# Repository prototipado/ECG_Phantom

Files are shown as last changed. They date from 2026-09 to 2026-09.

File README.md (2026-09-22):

# Fantoma ECG






Simulador y calibrador de señales electrocardíacas multicanal. Este proyecto integra el diseño de hardware analógico/digital, simulaciones de filtrado en LTSpice, implementaciones de firmware para RP2040 y RP2350, y software de control en Python.

## Arquitectura del sistema

```mermaid
flowchart TD
    subgraph HW["Hardware y Señal"]
        MCU["RP2040 / RP2350<br/>(Raspberry Pi Pico)"]
        FILT["Filtros Reconstrucción PWM/DAC<br/>(Simulados en LTSpice)"]
        OUT["Salida 9-12 Derivaciones ECG + PPG"]
        MCU --> FILT --> OUT
    end
    subgraph FW["Firmware"]
        FW1["01. Reproductor Clínico (Flash/PhysioNet)"]
        FW2["02. Modelo Conducción (VdP + FHN)"]
        FW3["03. Síntesis Gaussiana + PPG"]
        FW4["04. Multi-Modelo 4-en-1"]
        FW5["05. Simulador Marcapasos (Pacer)"]
    end
    FW -.->|Carga según aplicación| MCU
    subgraph SW["Software Host"]
        PY["ecg_gui.py (Python)"]
        PLOT["Monitoreo multicanal en tiempo real"]
        CFG["Configuración de parámetros"]
        PY --> PLOT
        PY --> CFG
    end
    MCU <== "Streaming Serie USB (Handshake binario / 2000 SPS)" ==> PY
```

## Estructura del repositorio

* [`hardware/`](./hardware/): Proyecto KiCad (`pico_ecg`), esquemáticos, PCB, huellas, modelos 3D, Gerber y BOM.
* [`simulaciones/`](./simulaciones/): Circuitos LTSpice para filtrado analógico (PWM a voltaje), detección de impulsos y scripts en Python.
* [`firmware/`](./firmware/): Código para Raspberry Pi Pico y Pico 2:
  * [`01_pico_ecg`](./firmware/01_pico_ecg/): Reproductor de registros clínicos guardados en memoria Flash.
  * Módulos adicionales en desarrollo (`02_pico_conduction_model` a `05_pace_sim`).
* [`software/`](./software/): Interfaz de escritorio en Python para visualización multicanal, registro de datos y control remoto.
* [`datasets/`](./datasets/): Registros de bases clínicas (PhysioNet, LUDB) y scripts para convertirlos a arreglos en C (`.h`).
* [`docs/`](./docs/): Protocolo de comunicación, referencias bibliográficas y notas de diseño.

## Características

* Salida de derivaciones estándar (I, II, III, aVR, aVL, aVF, V1-V6) y canal auxiliar PPG.
* Generación analógica a electrodos y transmisión serie por USB (hasta 2000 SPS).
* Control local mediante menú en pantalla OLED y encoder rotativo, o remoto desde la GUI en Python.
* Simulación de ritmos normales y patologías (taquicardia, bradicardia, fibrilación, bloqueos AV, deriva de línea base).

## Inicio rápido

### Dependencias de software (GUI)

```bash
cd software
python -m venv .venv

# En Windows:
.venv\Scripts\activate

# En Linux/macOS:
source .venv/bin/activate

pip install -r requirements.txt
python ecg_gui.py
```

### Carga de firmware

1. Navegar a la carpeta del firmware deseado (por ejemplo, [`firmware/01_pico_ecg/`](./firmware/01_pico_ecg/)).
2. Conectar la Raspberry Pi Pico manteniendo presionado el botón BOOTSEL.
3. Copiar el archivo `.uf2` compilado a la unidad USB generada.

## Estado del desarrollo

- [x] Caracterización y simulación de filtros pasa-bajos en LTSpice.
- [x] Firmware base `01_pico_ecg` para reproducción de registros clínicos.
- [ ] Desarrollo e integración de firmwares sintéticos (`02_pico_conduction_model` a `05_pace_sim`).
- [x] Diseños finales de PCB y acondicionamiento de señal en KiCad.
- [x] GUI en Python para captura en tiempo real, registro a CSV y compilación a ejecutable.

## Licencia

Este proyecto está bajo la Licencia MIT. Ver el archivo [`LICENSE`](./LICENSE) para más detalles.

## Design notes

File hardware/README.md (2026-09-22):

# Diseño de Hardware (KiCad)

Este directorio contiene el diseño electrónico y mecánico del Fantoma ECG, organizado como un proyecto unificado en KiCad.

## Estructura del proyecto

### Archivos de diseño KiCad

- **`pico_ecg.kicad_pro`**: Archivo principal del proyecto KiCad.
- **`pico_ecg.kicad_sch`**: Esquema de circuito principal (etapa analógica, microcontrolador y conectores).
- **`filtros.kicad_sch`**: Sub-esquema de la etapa de filtrado analógico.
- **`pacemaker.kicad_sch`**: Sub-esquema del simulador de marcapasos.
- **`pico_ecg.kicad_pcb`**: Ruteo de la placa de circuito impreso (PCB).

### Directorios

- **`pico_ecg.pretty/`**: Librería de huellas (footprints) locales utilizadas en el diseño — incluye huellas para OLED, Raspberry Pi Pico, cargador TP4056, encoder rotativo, entre otros.
- **`3d_models/`**: Modelos 3D de componentes (STEP/WRL) para visualización en KiCad — incluye Raspberry Pi Pico, OLED 0.96", cargador LiPo, encoder rotativo, y el ensamblaje completo (`pico_ecg.step`).
- **`case/`**: Archivos STL para impresión 3D del gabinete del dispositivo (`base.stl`, `frente.stl`) y fotografías del ensamblaje.
- **`gerber/`**: Archivos de fabricación (Gerber) y de perforación (Drill) listos para enviar a fabricación.
- **`bom/`**: Lista de materiales (`pico_ecg_BOM.csv`) con referencias de componentes, valores y huellas.
- **`docs/`**: Esquemático exportado en PDF (`pico_ecg.pdf`) para revisión rápida sin necesidad de KiCad.
- **`images/`**: Renderizados de la PCB y esquemas de filtrado.

## Imágenes

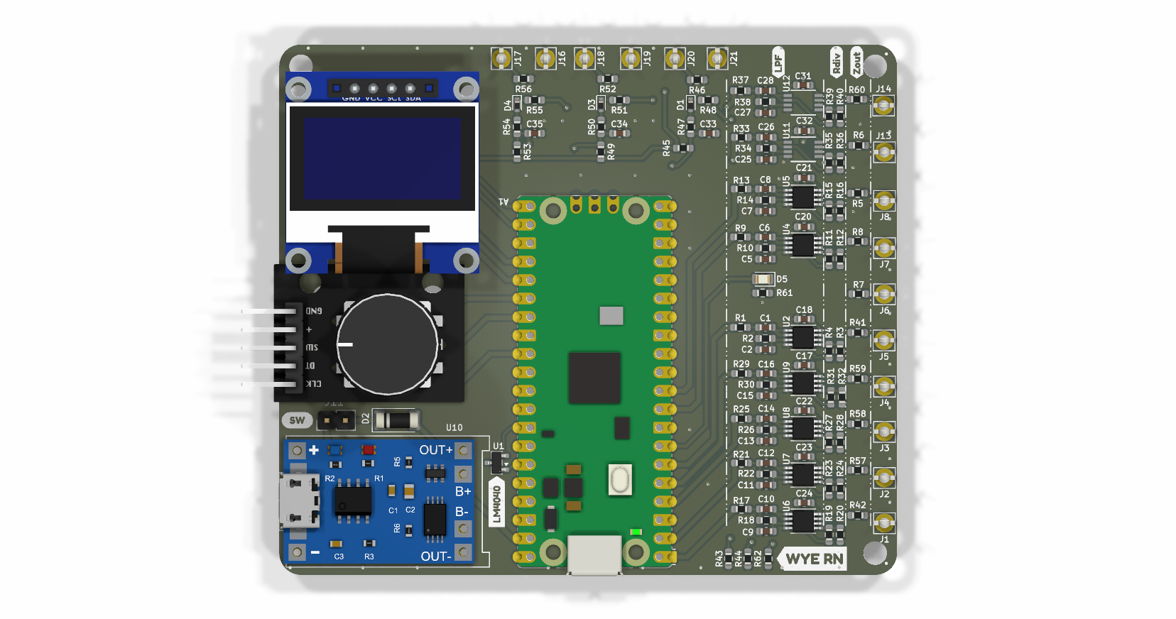
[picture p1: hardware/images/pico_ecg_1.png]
PCB renderizado — vista frontal

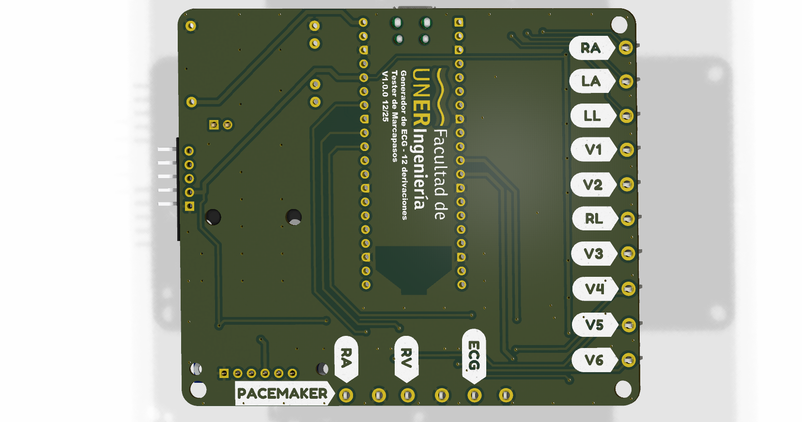
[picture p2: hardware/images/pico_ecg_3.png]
PCB renderizado — vista trasera


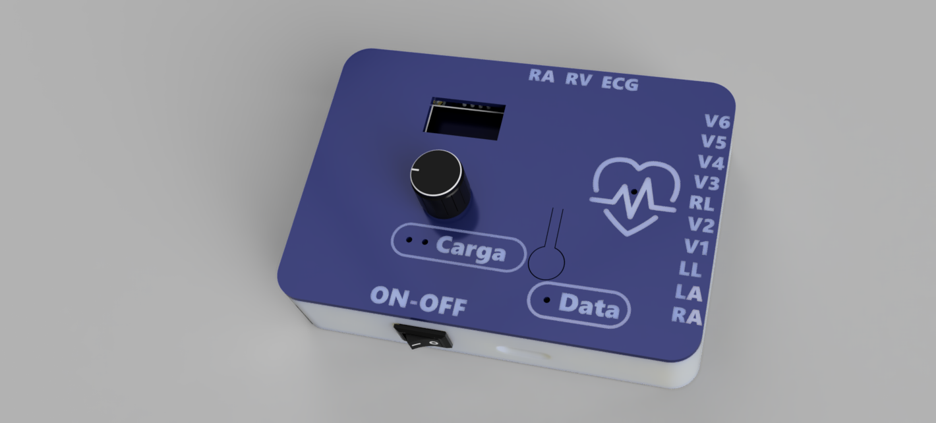
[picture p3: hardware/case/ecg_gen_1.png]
Generador ECG con carcasa impresa en 3D

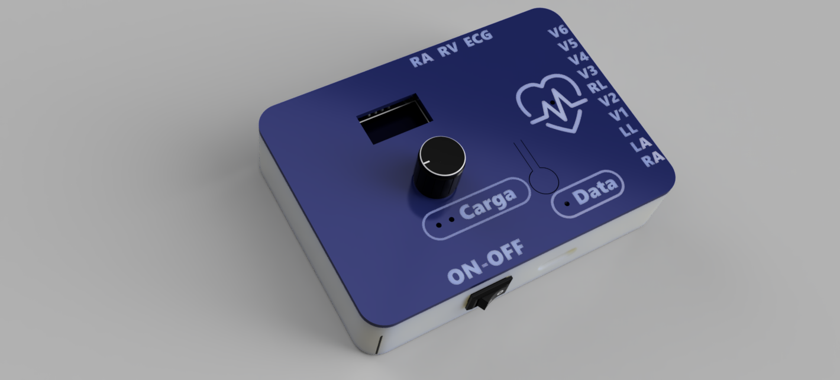
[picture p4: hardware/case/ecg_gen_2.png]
Generador ECG — vista lateral


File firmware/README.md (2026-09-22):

# Firmwares de Emulación Cardíaca (RP2040 / RP2350)

Este directorio alberga los módulos de firmware diseñados para microcontroladores Raspberry Pi Pico y Pico 2 (RP2040 / RP2350). Cada firmware aborda un método distinto de síntesis o reproducción de señales electrofisiológicas.

## Matriz de firmwares

| Carpeta | Nombre / Enfoque | Estado | Método de Generación | Salidas Soportadas | Complejidad Computacional |
|---|---|---|---|---|---|
| **`01_pico_ecg`** | Reproductor Clínico | Disponible | Lectura directa de Flash/RAM (PhysioNet) | 1 a 12 derivaciones | Baja (Look-up Table / DMA) |
| **`02_pico_conduction_model`** | Modelo Electrofisiológico | En desarrollo | Ecuaciones diferenciales acopladas (Van der Pol + FHN) | Derivaciones bipolares / derivaciones sintéticas | Media-Alta (Cálculo numérico RK4/Euler) |
| **`03_pico_gaussian_ppg`** | Síntesis Analítica + PPG | Planificado | Suma de curvas Gaussianas dinámicas | 9 derivaciones ECG + Pulso Óptico PPG | Media |
| **`04_pico_multimodel`** | Suite Multi-Motor 4-en-1 | Planificado | Selector de motor matemático en caliente | Multicanal configurable | Alta |
| **`05_pace_sim`** | Simulador de Marcapasos | Planificado | Inyección de espigas analógicas/digitales con tiempos configurables | Salida de estimulación cardíaca | Baja-Media |

## Módulo inicial: `01_pico_ecg`

Plataforma de reproducción de señales clínicas reales almacenadas en memoria Flash:
- **Salida multicanal:** 9 potenciales analógicos de electrodos (RA, LA, LL, V1–V6) generados vía moduladores PWM a 100 kHz.
- **Interfaz local:** Menú gráfico en pantalla OLED (SSD1306/SH1106 vía SPI) administrado con encoder rotativo mediante la librería GEM y u8g2.
- **Consola interactiva CLI USB:** Comandos serie (`> set`, `> get`, `> list`, `> play`, `> stop`, `> stream on/off`, `> ver`).
- **Streaming de alta velocidad:** Transmisión binaria IEEE 754 a 500 SPS compatible con `software/ecg_gui.py`.
- **Indicación auditiva y visual:** LED indicador y buzzer piezoeléctrico sincronizados con la onda R (complejo QRS).
- *Documentación detallada, pinout completo y comandos:* Consultar [firmware/01_pico_ecg/README.md](./01_pico_ecg/README.md).

## Componentes compartidos (`common/`)

Para evitar duplicar código, el directorio `common/` centraliza módulos compartidos configurados como librerías estáticas de CMake:

```text
firmware/
├── common/
│   ├── CMakeLists.txt     # Define los targets estáticos 'u8g2' y 'gem'
│   ├── GEM/               # Graphic Embedded Menu
│   └── u8g2/              # Librería gráfica u8g2/u8x8
├── 01_pico_ecg/           # Firmware de reproducción
└── 02_.../                # Otros firmwares
```

### Targets disponibles en `common`

1. **`u8g2`**: Compila el motor gráfico universal de displays monocromáticos.
2. **`gem`**: Compila el sistema de menús embebidos interactivo para encoders. Enlaza a `u8g2` de forma `PUBLIC`, heredando sus archivos de cabecera.

### Cómo integrar `common` en un nuevo firmware

Para crear un nuevo firmware (ej. `02_pico_conduction_model`) que haga uso de GEM y u8g2, en su `CMakeLists.txt` se debe:

```cmake
# 1. Registrar el subdirectorio 'common'
add_subdirectory(${CMAKE_CURRENT_LIST_DIR}/../common ${CMAKE_CURRENT_BINARY_DIR}/common_build)

# 2. Agregar el ejecutable
add_executable(mi_firmware 
    main.c
)

# 3. Vincular 'gem' (propaga u8g2 automáticamente)
target_link_libraries(mi_firmware 
    gem
    pico_stdlib
    hardware_spi
)
```

Nota: CMake propaga automáticamente las rutas de include públicas (`common/GEM` y `common/u8g2/csrc`) a cualquier ejecutable que enlace la librería `gem` o `u8g2`.

## Guía de compilación

Todos los firmwares utilizan el Raspberry Pi Pico SDK (v2.x) y CMake.

### 1. Requisitos previos

- Raspberry Pi Pico SDK 2.x instalado (`PICO_SDK_PATH`).
- Toolchain GCC para ARM Cortex-M: `arm-none-eabi-gcc` (v12 o superior).
- CMake (v3.13 o superior) y Ninja (recomendado).
- Opcional: Visual Studio Code con la extensión oficial de Raspberry Pi Pico.

### 2. Compilación desde la terminal

Navegar a la carpeta del firmware que se desea compilar:

```powershell
# Entrar al firmware
cd firmware/01_pico_ecg

# Generar los archivos de compilación
cmake -G Ninja -B build -S .

# Compilar
ninja -C build
```

Si no se dispone de Ninja:
```powershell
cmake -B build -S .
cmake --build build
```

### 3. Compilación desde Visual Studio Code

1. Abrir la carpeta del firmware (por ejemplo `firmware/01_pico_ecg`) en VS Code.
2. La extensión de Raspberry Pi Pico detectará el archivo `.vscode/settings.json`.
3. Presionar `Ctrl + Shift + B` o hacer clic en "Compile Project".

### 4. Carga en la placa (flasheo)

En la carpeta `build/` se generará un archivo `.uf2`:

1. Conectar la Raspberry Pi Pico / Pico 2 a la PC manteniendo presionado el botón BOOTSEL.
2. Aparecerá una unidad de almacenamiento USB (`RPI-RP2` o `RP2350`).
3. Copiar el archivo `.uf2` dentro de la unidad.
4. El microcontrolador se reiniciará automáticamente.

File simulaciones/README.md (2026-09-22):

# Simulaciones de Circuitos y Filtros

Modelos en LTSpice y scripts de procesamiento en Python para el diseño, simulación y validación de las etapas analógicas del Fantoma ECG.

## Contenido del directorio

### 1. Modelos de circuito (`ltspice/`)

* **`filter_pwm.asc`**: Simulación transitoria en el dominio del tiempo del filtro pasa-bajos activo/pasivo. Modela la reconstrucción analógica continua a partir de la señal modulada por ancho de pulsos (PWM) generada por el microcontrolador.
* **`filter_pwm_ac.asc`**: Análisis en el dominio de la frecuencia (barrido AC / Diagrama de Bode) para determinar la frecuencia de corte (-3 dB), la linealidad en la banda de paso médica (0.05 Hz – 150 Hz) y la atenuación de la frecuencia portadora PWM.
* **`pace_input_circuit.asc`**: Etapa analógica de acondicionamiento y sensado para detección de impulsos y espigas de marcapasos artificiales.

### 2. Estímulos y tablas de tensión PWL (`ltspice/`)

* **`ecg_pwl.txt`**: Datos de señal electrocardíaca formateados en pares `(tiempo, voltaje)` para alimentar fuentes dependientes PWL en simulaciones transitorias.
* **`ECG-LTSPICE.txt`**: Trazado cardíaco en sintaxis nativa de LTSpice `(t1 v1 t2 v2 ...)`.
* **`pace_pulse_train_rc.txt`**: Tren de pulsos periódicos con decaimiento RC característico para probar la respuesta del circuito de detección de marcapasos.

### 3. Scripts de análisis y visualización (`scripts/`)

* **`data_graph.py`**: Script de Python optimizado para procesar datos exportados desde LTSpice:
  * Emplea el motor C de `pandas` para lectura rápida.
  * Implementa submuestreo (`MAX_PUNTOS = 50000`) para renderizado fluido.
  * Genera dos vistas:
    1. Desglose individual: Visualización multicanal de tensiones intermedias.
    2. Comparación de fidelidad: Superposición entre la señal original (`V(v_sig)`) y la señal filtrada (`V(n002)`).
* **`pwm_gen.py`**: Convierte tablas de señales en formato C (`.h`) a archivos de estímulo por tramos PWL (`ecg_pwl.txt`) para LTSpice, normalizando la amplitud al rango dinámico del PWM (0 a 3.3V / 16 bits).
* **`Figure_1.png`**, **`Figure_2.png`**: Gráficas resultantes del análisis temporal.

## Resultados de simulación

| Desglose de Nodos (Figura 1) | Reconstrucción Original vs. Filtrada (Figura 2) |
|:---:|:---:|
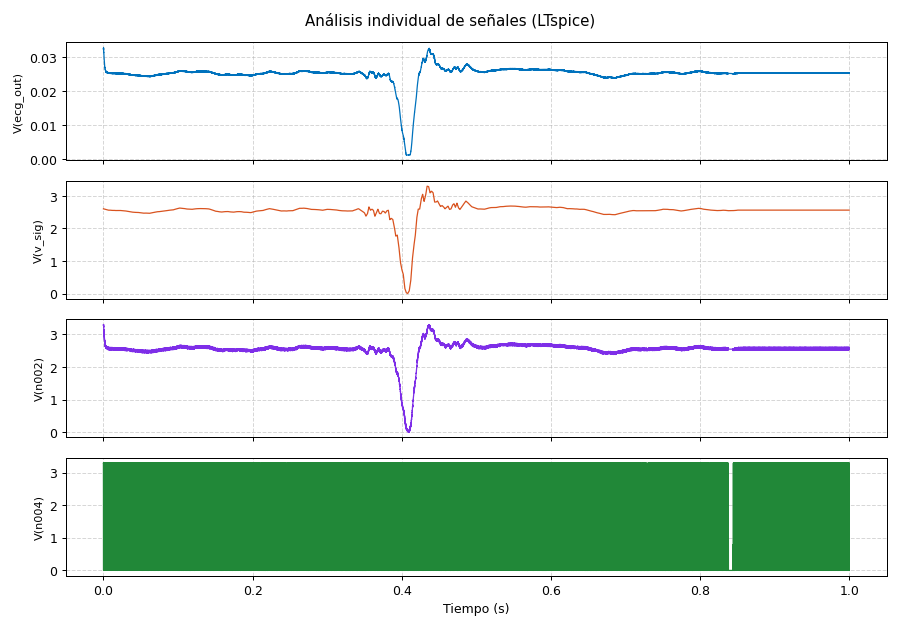
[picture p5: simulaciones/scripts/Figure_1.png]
Análisis individual
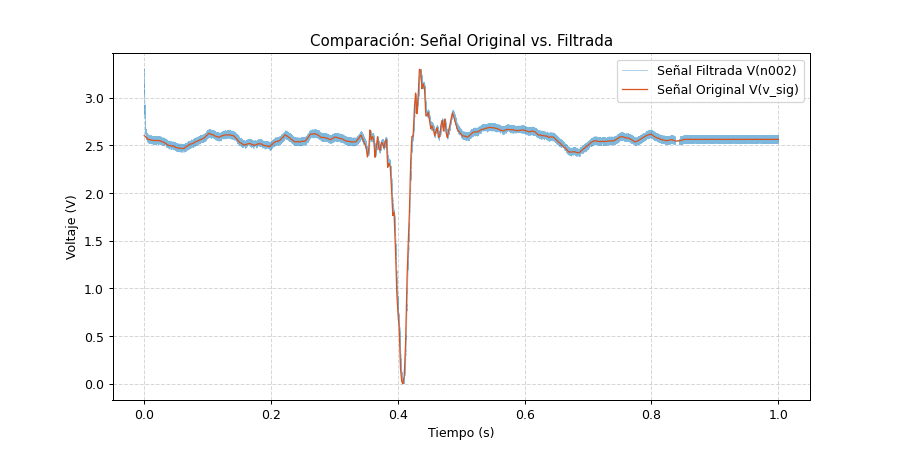
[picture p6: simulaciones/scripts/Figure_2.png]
Comparación
|  |  |

## Flujo de trabajo para simulaciones

1. **Abrir y simular en LTSpice:**
   - Abrir `ltspice/filter_pwm.asc` en LTSpice.
   - Ejecutar la simulación Transitoria.
2. **Exportar datos desde LTSpice:**
   - `File` → `Export data as text`.
   - Seleccionar las variables de interés (ej. `V(v_sig)`, `V(n002)`).
   - Guardar como `filter_pwm_out_signals.txt` en `simulaciones/scripts/`.
3. **Generar gráficos:**
   ```bash
   cd simulaciones/scripts
   python data_graph.py
   ```

Nota: Los archivos de simulación de gran tamaño y los binarios generados por LTSpice (.raw, .log) están excluidos del repositorio mediante `.gitignore`.

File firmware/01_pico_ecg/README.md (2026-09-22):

# Monitor y Reproductor ECG pico_ecg

Plataforma de reproducción y monitoreo de electrocardiografía basada en Raspberry Pi Pico y Pico 2 (RP2040 / RP2350). Permite la reproducción de registros electrocardíacos almacenados en memoria flash, generación de ondas sintéticas, control por menú OLED con encoder, consola CLI interactiva y transmisión serie en tiempo real.

## Características

- **Reproducción de registros clínicos**: Señales ECG de 9 derivaciones provenientes de bases de datos como LUDB, guardadas en flash.
- **Generador de calibración**: Ondas sintéticas (Seno, Cuadrada, Triangular, Pulso).
- **Salida PWM (100 kHz)**: Generación analógica de 9 potenciales de electrodos (RA, LA, LL, V1–V6) mediante PWM filtrado.
- **Menú OLED (GEM)**: Interfaz gráfica en pantallas OLED (SH1106 / SSD1306 vía SPI) controlada por encoder rotativo.
- **Consola CLI USB CDC**: Interfaz de comandos en tiempo real por el puerto serie USB.
- **Streaming binario**: Emisión de paquetes binarios (float32) a 500 SPS compatibles con el software en Python.
- **Indicación QRS**: LED y buzzer piezoeléctrico sincronizados con la onda R.

## Hardware y mapeo de pines

| Periférico | Pin GPIO | Descripción |
| :--- | :--- | :--- |
| **PWM RA (Ref)** | GPIO 0 | Brazo Derecho (Referencia 0V) |
| **PWM LA (Deriv I)** | GPIO 1 | Brazo Izquierdo |
| **PWM LL (Deriv II)**| GPIO 2 | Pierna Izquierda |
| **PWM V1 – V6** | GPIO 3, 4, 6, 7, 8, 9 | Precordiales V1 a V6 |
| **LED QRS** | GPIO 5 | Indicador de pico R |
| **Buzzer** | GPIO 15 | Feedback auditivo QRS |
| **OLED SPI0 DC** | GPIO 16 | Data / Command para display OLED |
| **OLED SPI0 RST** | GPIO 17 | Reset de OLED |
| **OLED SPI0 SCK** | GPIO 18 | Reloj SPI (1 MHz) |
| **OLED SPI0 MOSI**| GPIO 19 | Salida de datos SPI |
| **Encoder Button** | GPIO 20 | Pulsador (Pull-up interno) |
| **Encoder DATA** | GPIO 21 | Canal A |
| **Encoder CLK** | GPIO 22 | Canal B |
| **USB Sense** | GPIO 24 | Detección VBUS |
| **Pico LED** | GPIO 25 | LED integrado |
| **Batería ADC** | GPIO 29 (ADC3) | Medición de batería (divisor de tensión) |

## Interfaz de línea de comandos (CLI)

El puerto USB CDC opera a 115200 baudios. Los comandos se ingresan utilizando el prefijo `>`.

### Comandos disponibles

| Comando | Descripción | Ejemplo |
| :--- | :--- | :--- |
| `> help` | Lista de comandos | `> help` |
| `> set <param> <val>`| Modifica un parámetro | `> set hr 75` |
| `> get [param]` | Consulta parámetros | `> get hr` |
| `> list` | Lista archivos ECG en memoria | `> list` |
| `> play` | Inicia la generación | `> play` |
| `> stop` | Detiene la generación | `> stop` |
| `> stream <on\|off>` | Transmisión binaria a 500 SPS | `> stream on` |
| `> ver` | Versión del firmware | `> ver` |

### Parámetros para comando `set`

- `type <ecg|sine|tri|sq|pulse>`: Tipo de onda.
- `hr <30-240>`: Frecuencia cardíaca (BPM).
- `amp <0-100>`: Amplitud de salida (%).
- `offset <-16384 a 16384>`: Desplazamiento DC.
- `file <0-N>`: Índice del registro ECG en flash.
- `buzzer <on|off>`: Activa/desactiva sonido.
- `led <on|off>`: Activa/desactiva indicador QRS.

## Protocolo binario de streaming

Al ejecutar `> stream on`, se transmiten paquetes binarios a 500 Hz por puerto USB:

```
[0xAA 0x55] [Float CH0] [Float CH1] ... [Float CH8] [0x55 0xAA]
```

- **Cabecera**: 2 bytes Sync `0xAA 0x55`.
- **Datos**: 9 valores `float` (32 bits, IEEE-754 little-endian) correspondientes a RA, LA, LL, V1 a V6.
- **Cierre**: 2 bytes Sync `0x55 0xAA`.
- **Tamaño total**: 40 bytes.

## Diagrama de flujo del firmware

```mermaid
flowchart TD
    SRC1["Registros clínicos en Flash"] --> SEL["Selección de fuente"]
    SRC2["Ondas de calibración"] --> SEL
    SEL --> GEN["signal_gen"]
    GEN --> PWM["9 salidas PWM 100 kHz"]
    GEN --> QRS["Indicación QRS (LED/Buzzer)"]
    GEN --> STREAM["Streaming binario USB (500 SPS)"]
    STREAM --> GUI["ecg_gui.py en PC"]
```

## Estructura del menú OLED (GEM)

Navegación mediante encoder rotativo:
- **Giro**: Desplazar selección / ajustar valores.
- **Pulsación Corta**: Aceptar / Entrar.
- **Pulsación Larga**: Volver / Cancelar.

```
MAIN MENU
├── Signal
│   ├── Type (ECG, Sine, Triangle, Square, Pulse)
│   ├── Heart Rate (30-240 BPM)
│   ├── Amplitude (0-100%)
│   └── Offset
├── Playback
│   ├── Play/Pause
│   └── Loop Enable
├── Output
│   ├── Gain
│   └── Offset
├── Interface
│   ├── LED Mode
│   └── Buzzer
├── Files
│   ├── Select ECG
│   └── File Info
└── System
    ├── Firmware Info
    └── Battery Voltage
```

## Incorporación de nuevas señales (.h)

Para agregar nuevos registros ECG:

1. Convertir el registro a un archivo de cabecera C (`.h`) con la estructura `ecg_struct_t`.
2. Guardar el archivo en `Signals/`.
3. Ejecutar el script: `python fix_signal_headers.py`.
4. Abrir `Drivers/src/signal_registry.c`.
5. Incluir la cabecera: `#include "../../Signals/nuevo_registro.h"`.
6. Añadir el puntero a la tabla `registry[]`: `{ "Nombre", &Estructura_Signal },`.
7. Recompilar y flashear.

## Compilación

Requisitos:
- Pico SDK 2.x.
- CMake y Ninja (o Make).
- Toolchain arm-none-eabi-gcc.

Pasos:
```powershell
mkdir build
cd build
cmake .. -G "Ninja"
ninja
```

Se generará `pico_ecg.uf2`. Copiarlo a la unidad de almacenamiento RPI-RP2 en modo BOOTSEL.

## Fundamento electrofisiológico

El simulador inyecta los potenciales de los electrodos respecto a la referencia común:

- **Derivaciones bipolares**:
  $$I = V_{LA} - V_{RA}$$
  $$II = V_{LL} - V_{RA}$$
  $$III = V_{LL} - V_{LA}$$

Asumiendo $V_{RA} = 0$, se inyecta $V_{LA} = I$ y $V_{LL} = II$.
Las precordiales $V_1$ a $V_6$ se sintetizan en sus correspondientes PWM.

La referencia de Wilson (WCT) es reconstruida por el equipo receptor. El terminal de pierna derecha (RL) debe conectarse a tierra con alta impedancia.

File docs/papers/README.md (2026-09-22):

# Modelos de señales ECG / PPG

Este repositorio contiene implementaciones, experimentos y herramientas basadas en modelos matemáticos descritos en publicaciones científicas para la generación y simulación de señales fisiológicas, principalmente señales ECG y PPG.

Las implementaciones incluidas en este repositorio son desarrolladas y mantenidas de forma independiente de las publicaciones originales y de sus respectivas editoriales.

---

## Publicaciones de referencia

### 1. Emulador fisiológico ECG–PPG — 2026

**Huynh, T. V., Tran, T. N., & Tran, A. T. (2026).**

*An ECG–PPG Physiological Signal Emulator for Calibration and Validation of Cardiovascular Monitoring Devices.*

**Sensors, 26, 5578.**

DOI: https://doi.org/10.3390/s26175578

El artículo fue publicado en acceso abierto bajo la licencia **Creative Commons Attribution 4.0 International (CC BY 4.0)**.

El artículo original puede ser redistribuido de acuerdo con los términos de dicha licencia, manteniendo la atribución correspondiente.

---

### 2. Simulador de paciente ECG basado en modelos matemáticos — 2022

**Quiroz-Juárez, M. A., Rosales-Juárez, J. A., Jiménez-Ramírez, O., Vázquez-Medina, R., & Aragón, J. L. (2022).**

*ECG Patient Simulator Based on Mathematical Models.*

**Sensors, 22, 5714.**

DOI: https://doi.org/10.3390/s22155714

El artículo fue publicado en acceso abierto bajo la licencia **Creative Commons Attribution 4.0 International (CC BY 4.0)**.

El artículo original puede ser redistribuido de acuerdo con los términos de dicha licencia, manteniendo la atribución correspondiente.

---

### 3. Modelo de conducción cardíaca para la generación de ECG de 12 derivaciones — 2018

**Quiroz-Juárez, M. A., Jiménez-Ramírez, O., Vázquez-Medina, R., Ryzhii, E., Ryzhii, M., & Aragón, J. L. (2018).**

*Cardiac Conduction Model for Generating 12 Lead ECG Signals With Realistic Heart Rate Dynamics.*

**IEEE Transactions on NanoBioscience, 17(4), 525–532.**

DOI: https://doi.org/10.1109/TNB.2018.2870331

La publicación original pertenece a **IEEE** y está sujeta a las condiciones de copyright y distribución de IEEE.

El artículo completo de IEEE **no se redistribuye en este repositorio**.

El artículo original y los recursos asociados de algoritmos/código están disponibles en IEEE Xplore:

https://ieeexplore.ieee.org/document/8466837/algorithms?tabFilter=code

La implementación incluida en este repositorio es una implementación independiente basada en la metodología y el modelo matemático descritos en la publicación de referencia.

---

## Licencias

Este repositorio contiene diferentes tipos de material, que pueden estar sujetos a diferentes condiciones de licencia.

### Código fuente de este repositorio

Salvo que se indique lo contrario en archivos o directorios específicos, el código fuente desarrollado específicamente para este repositorio se distribuye bajo la licencia indicada en el archivo `LICENSE`.

### Publicaciones científicas

Los dos artículos publicados en **Sensors** mencionados anteriormente se distribuyen bajo la licencia **Creative Commons Attribution 4.0 International (CC BY 4.0)**, de acuerdo con sus respectivas publicaciones.

El artículo publicado por **IEEE** en 2018 mantiene las condiciones de copyright y distribución de IEEE y su PDF no se redistribuye en este repositorio.

### Material de terceros

Cualquier código fuente, conjunto de datos, figura, imagen u otro material de terceros incluido en este repositorio conserva su licencia original, salvo que se indique expresamente lo contrario.

El usuario de este repositorio es responsable de respetar las condiciones de licencia aplicables al material de terceros.

---

## Atribución

Si utiliza una implementación o adaptación de este repositorio en un trabajo académico o técnico, se recomienda citar la publicación científica correspondiente.

### 2026 — Emulador ECG–PPG

```text
Huynh, T. V., Tran, T. N., & Tran, A. T.
"An ECG–PPG Physiological Signal Emulator for Calibration and
Validation of Cardiovascular Monitoring Devices."
Sensors, vol. 26, 5578, 2026.
https://doi.org/10.3390/s26175578
```

### 2022 — Simulador de paciente ECG

```text
Quiroz-Juárez, M. A., Rosales-Juárez, J. A., Jiménez-Ramírez, O.,
Vázquez-Medina, R., & Aragón, J. L.
"ECG Patient Simulator Based on Mathematical Models."
Sensors, vol. 22, 5714, 2022.
https://doi.org/10.3390/s22155714
```

### 2018 — Modelo de conducción cardíaca

```text
Quiroz-Juárez, M. A., Jiménez-Ramírez, O., Vázquez-Medina, R.,
Ryzhii, E., Ryzhii, M., & Aragón, J. L.
"Cardiac Conduction Model for Generating 12 Lead ECG Signals
With Realistic Heart Rate Dynamics."
IEEE Transactions on NanoBioscience, vol. 17, no. 4,
pp. 525–532, 2018.
https://doi.org/10.1109/TNB.2018.2870331
```

---

## Aviso

Este repositorio es un proyecto de software independiente destinado a investigación, desarrollo, simulación, educación y pruebas.

No está afiliado, patrocinado ni respaldado por **MDPI, IEEE** ni por los autores de las publicaciones de referencia, salvo que se indique expresamente lo contrario.

Las implementaciones proporcionadas en este repositorio no deben interpretarse como dispositivos médicos validados ni como sustitutos de equipos clínicos, ensayos clínicos o procesos de validación regulatoria.

---

## Referencias

1. Huynh, T. V., Tran, T. N., & Tran, A. T. (2026). *An ECG–PPG Physiological Signal Emulator for Calibration and Validation of Cardiovascular Monitoring Devices.* Sensors, 26, 5578. https://doi.org/10.3390/s26175578

2. Quiroz-Juárez, M. A., Rosales-Juárez, J. A., Jiménez-Ramírez, O., Vázquez-Medina, R., & Aragón, J. L. (2022). *ECG Patient Simulator Based on Mathematical Models.* Sensors, 22, 5714. https://doi.org/10.3390/s22155714

3. Quiroz-Juárez, M. A., Jiménez-Ramírez, O., Vázquez-Medina, R., Ryzhii, E., Ryzhii, M., & Aragón, J. L. (2018). *Cardiac Conduction Model for Generating 12 Lead ECG Signals With Realistic Heart Rate Dynamics.* IEEE Transactions on NanoBioscience, 17(4), 525–532. https://doi.org/10.1109/TNB.2018.2870331

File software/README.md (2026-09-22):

# Software Host en Python (GUI de Monitoreo y Control)

Aplicación de escritorio desarrollada en Python (Tkinter + Matplotlib) para la conexión, configuración de parámetros y visualización multicanal de señales del Fantoma ECG.

## Características principales

- **Streaming serie USB**: Comunicación a 921600 baudios para recepción de tramas binarias a tasas de hasta 2000 SPS.
- **Autodetección de firmware**: Identifica el módulo de hardware conectado y adapta los controles y derivaciones disponibles (reproducción clínica, modelos electrofisiológicos, síntesis, etc.).
- **Visualizador multicanal**: Renderizado de señales utilizando búferes de NumPy y submuestreo para mantener fluidez en diferentes ventanas de tiempo.
- **Control de parámetros**: Ajuste en tiempo real de variables electrofisiológicas.
- **Detección de marcapasos**: Panel de configuración de umbrales atriales/ventriculares y tiempos refractarios (disponible según el firmware).
- **Registro de datos**:
  - Exportación de muestras a CSV con marcas de tiempo en microsegundos.
  - Guardado de capturas de pantalla de las gráficas.
- **Terminal serie**: Monitor integrado para ver la transmisión de datos y comandos.
- **Cálculo de frecuencia cardíaca**: Detección de picos R y estimación de BPM en tiempo real.

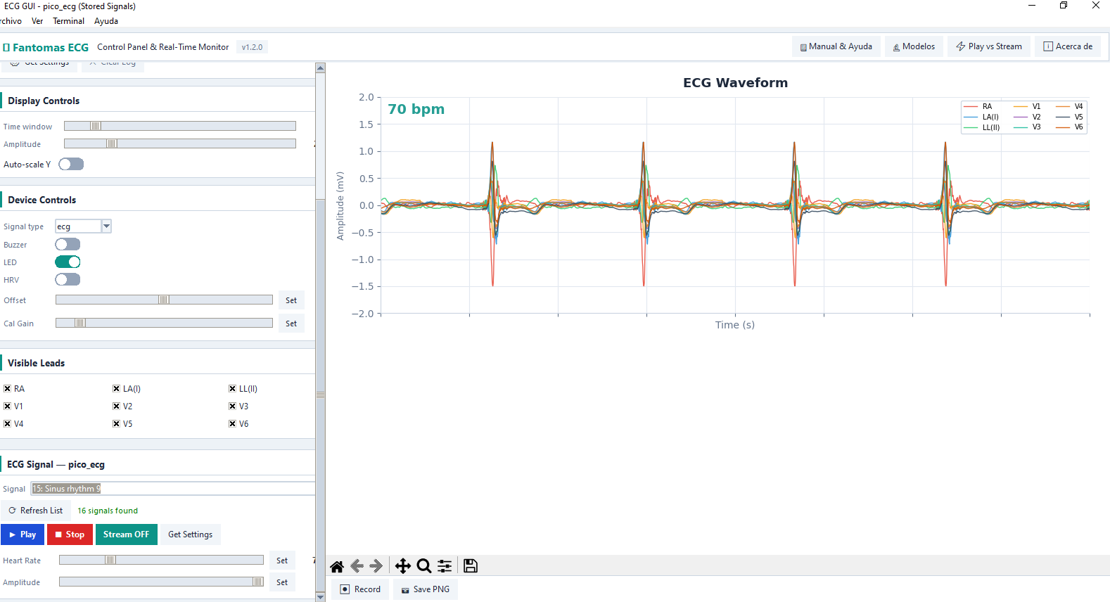
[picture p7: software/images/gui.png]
Interface ECG conectado al Firmware 01_pico_ecg


## Ejecución desde código fuente (Python)

### 1. Requisitos previos
- Python 3.9 o superior.
- Se recomienda el uso de un entorno virtual:

```bash
cd software
python -m venv .venv

# En Windows:
.venv\Scripts\activate

# En Linux / macOS:
source .venv/bin/activate
```

### 2. Instalar dependencias
```bash
pip install -r requirements.txt
```

### 3. Iniciar la aplicación
```bash
python ecg_gui.py
```

## Compilación a ejecutable independiente (.exe)

Para distribuir la aplicación a usuarios de Windows sin requerir instalación de Python:

1. Ejecutar el script automatizado de compilación:
   ```cmd
   build_exe.bat
   ```
2. El script verificará las dependencias (PyInstaller) y generará un ejecutable en:
   ```
   software/dist/ECG_GUI.exe
   ```

Nota: La carpeta `dist/` y los ejecutables `.exe` están excluidos del repositorio Git.

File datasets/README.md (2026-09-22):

# Bases de Datos y Registros Clínicos

Este directorio contiene bases de datos clínicas originales, scripts de preprocesamiento y extracción de ciclos cardíacos, y las tablas de datos en C (`.h`) para ser embebidas en la memoria de los microcontroladores.

## Estructura del directorio

```
datasets/
├── raw/                      # Registros clínicos originales
│   └── lobachevsky-university-electrocardiography-database-1.0.1/
├── scripts/                  # Herramientas de extracción y conversión
│   └── generacion_de_senales.ipynb
├── header_arrays/            # Tablas C (.h) generadas para el firmware
│   ├── Sinus_rhythm.h
│   ├── Sinus_bradycardia.h
│   ├── Atrial_fibrillation_N_51.h
│   └── ...
└── processed/                # Señales intermedias procesadas
```

## 1. Datos clínicos originales (`raw/`)

* **Lobachevsky University Electrocardiography Database (LUDB)**:
  * Base de datos clínica de referencia alojada en PhysioNet.
  * Contiene 200 registros electrocardiográficos estándar de 12 derivaciones (I, II, III, aVR, aVL, aVF, V1–V6).
  * Incluye anotaciones detalladas de ritmos, anomalías de conducción, hipertrofias, isquemia y extrasístoles (`ludb.csv`).

## 2. Scripts de conversión (`scripts/`)

* **`generacion_de_senales.ipynb`**:
  * Emplea la librería `wfdb` para la lectura directa de los registros.
  * Detecta los picos QRS y analiza las derivaciones para aislar ciclos cardíacos completos.
  * Algoritmo de empatamiento: selecciona el ciclo donde la amplitud inicial es cercana a la final, garantizando una reproducción continua en bucle sin discontinuidades abruptas.
  * Aplica offset y factor de escala para DAC / PWM de 12 a 16 bits.
  * Exporta el arreglo multidimensional a un archivo de cabecera en C (`.h`) en `header_arrays/`.

## 3. Tablas de cabecera C (`header_arrays/`)

Archivos `.h` formateados para compilación con el SDK de Raspberry Pi Pico:

| Archivo | Patología / Ritmo | Paciente ID | Descripción |
|---|---|---|---|
| **`Sinus_rhythm.h`** | Ritmo Sinusal Normal | 1 | Trazado sinusal de referencia |
| **`Sinus_rhythm_N_*.h`** | Ritmo Sinusal Normal | 11, 21, 31, 45, 46, 55, 66 | Variaciones morfológicas individuales |
| **`Sinus_bradycardia.h`** | Bradicardia Sinusal | Base | Frecuencia cardíaca baja (<60 BPM) |
| **`Sinus_bradycardia_N_*.h`**| Bradicardia Sinusal | 41, 47 | Casos clínicos con bradicardia |
| **`Atrial_fibrillation_N_51.h`**| Fibrilación Auricular | 51 | Pérdida de onda P y ritmo irregular |

### Formato de datos en C

Cada archivo define una estructura `ecg_struct_t` con metadatos clínicos y la matriz de datos:

```c
#include "ecg_types.h"

#define ROWS_46 391
#define COLS_46 12

static const int ecg_array[ROWS_46][COLS_46] = {
    {30058, 29998, 29938, ...},
    ...
};

ecg_struct_t Sinus_rhythm_N_46 = {
    .rhythms = "SINUS RHYTHM",
    .cond_abnor = "NONE",
    .rows = ROWS_46,
    .cols = COLS_46,
    .array = ecg_array
};
```

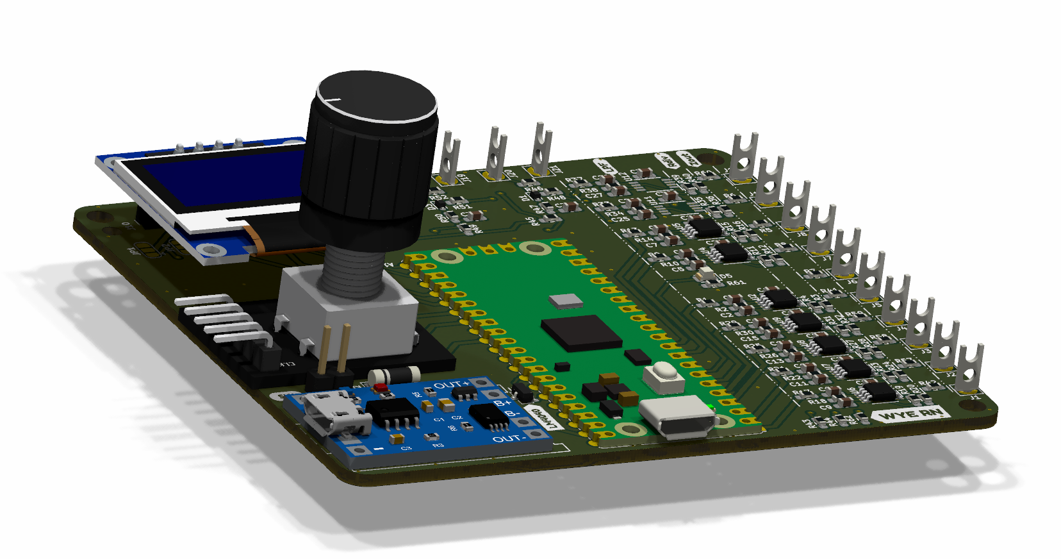
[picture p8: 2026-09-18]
hardware/images/pico_ecg_2.png

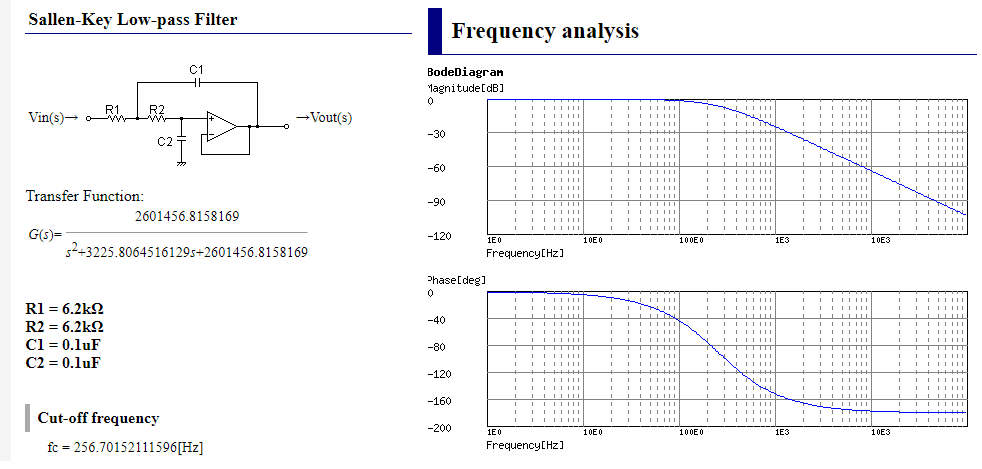
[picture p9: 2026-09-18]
hardware/images/filtro.png

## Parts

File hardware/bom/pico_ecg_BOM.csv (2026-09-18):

Reference | Footprint | DNP | Descripción | Distribuitor PN | Distribuitor | Manufacturer
A1 | Module:RaspberryPi_Pico_Common_Unspecified |  | RASPBERRY PI PICO 2 RP2350 | 2648-SC1631CT-ND | Digikey | Raspberry Pi
C1,C2,C5,C6,C7,C8,C9,C10,C11,C12,C13,C14,C15,C16,C17,C18,C20,C21,C22,C23,C24,C25,C26,C27,C28,C31,C32,C33,C34,C35 | Capacitor_SMD:C_0603_1608Metric_Pad1.08x0.95mm_HandSolder |  | CAP CER 0.1UF 50V X7R 0603 | 399-C0603C104K5RACTUCT-ND | Digikey | KEMET
D1,D3,D4 | Diode_SMD:D_SOD-523 |  | DIODE STANDARD 80V 125MA SOD523 | 1N4148WTDICT-ND | Digikey | Diodes Incorporated
D2 | Diode_SMD:D_MELF
D5 | LED_SMD:LED_0805_2012Metric |  | LED RED CLEAR SMD | 160-1427-1-ND | Digikey | Lite-On Inc.
J1,J2,J3,J4,J5,J6,J7,J8,J13,J14,J16,J17,J18,J19,J20,J21 | Connector_Pin:Pin_D1.4mm_L8.5mm_W2.8mm_FlatFork
J9 | Connector_PinSocket_2.54mm:PinSocket_1x05_P2.54mm_Vertical |  | CONN RCPT 5POS 0.1 TIN PCB | 612-SSW-105-01-T-S-ND | Digikey | Samtec Inc.
J10 | Connector_PinSocket_2.54mm:PinSocket_1x06_P2.54mm_Vertical |  | CONN RCPT 6POS 0.1 TIN PCB | 612-SSW-106-01-T-S-ND | Digikey | Samtec Inc.
J11 | Connector_PinHeader_2.54mm:PinHeader_1x02_P2.54mm_Vertical |  | CONN HEADER VERT 2POS 2.54MM | SAM10844-ND | Digikey | Samtec Inc.
JP1,JP2,JP3 | Jumper:SolderJumper-3_P1.3mm_Open_RoundedPad1.0x1.5mm
R1,R2,R9,R10,R13,R14,R17,R18,R21,R22,R25,R26,R29,R30,R33,R34,R37,R38 | Resistor_SMD:R_0603_1608Metric_Pad0.98x0.95mm_HandSolder |  | RES 6.2K OHM 5% 1/10W 0603 | 311-6.2KGRCT-ND | Digikey | YAGEO
R3,R12,R16,R20,R24,R28,R32,R36,R40,R46,R48,R51,R52,R55,R56 | Resistor_SMD:R_0603_1608Metric_Pad0.98x0.95mm_HandSolder |  | RES 1K OHM 5% 1/10W 0603 | 311-1.0KGRCT-ND | Digikey | YAGEO
R4,R7,R11,R15,R19,R23,R27,R31,R35,R39,R43,R44,R45,R47,R49,R50,R53,R54,R62 | Resistor_SMD:R_0603_1608Metric_Pad0.98x0.95mm_HandSolder |  | RES 100K OHM 5% 1/10W 0603 | 311-100KGRCT-ND | Digikey | YAGEO
R5,R6,R8,R41,R42,R57,R58,R59,R60,R61 | Resistor_SMD:R_0603_1608Metric_Pad0.98x0.95mm_HandSolder |  | RES 470 OHM 5% 1/10W 0603 | 311-470GRCT-ND | Digikey | YAGEO
U1 | Package_TO_SOT_SMD:SOT-23 |  | IC VREF SHUNT 0.5% SOT23-3 | LM4040CIM3-2.0/NOPBCT-ND | Digikey | Texas Instruments
U2,U4,U5,U6,U7,U8,U9,U11,U12 | pico_ecg:DGK8-L |  | IC OP AMP 2CH 8-VSSOP | 296-22883-1-ND | Digikey | Texas Instruments
U10 | pico_ecg:TP4056_w_protection

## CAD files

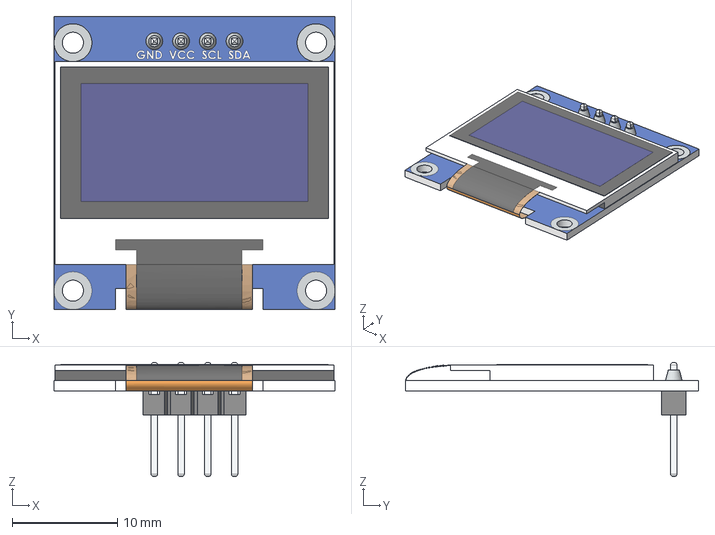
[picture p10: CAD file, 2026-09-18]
hardware/3d_models/OLED-128x64-0.96.step
26.7 x 27.9 x 10.8 mm

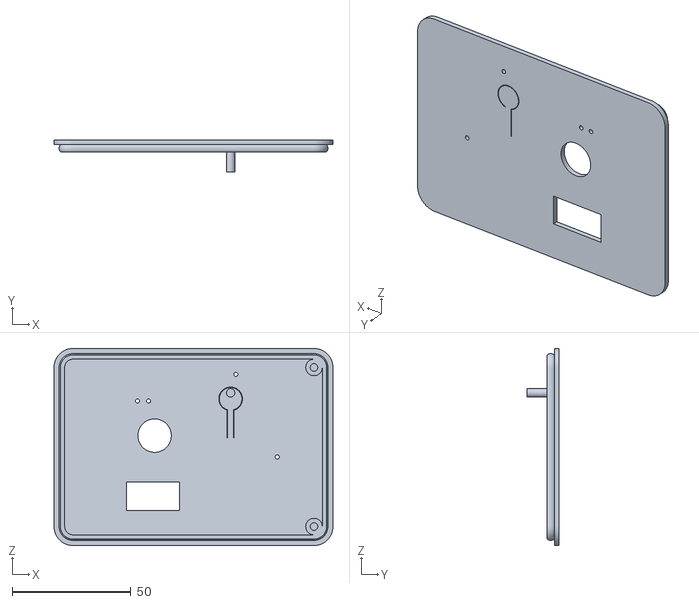
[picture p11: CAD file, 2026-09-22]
hardware/case/frente.stl
117.5 x 13.5 x 83.0

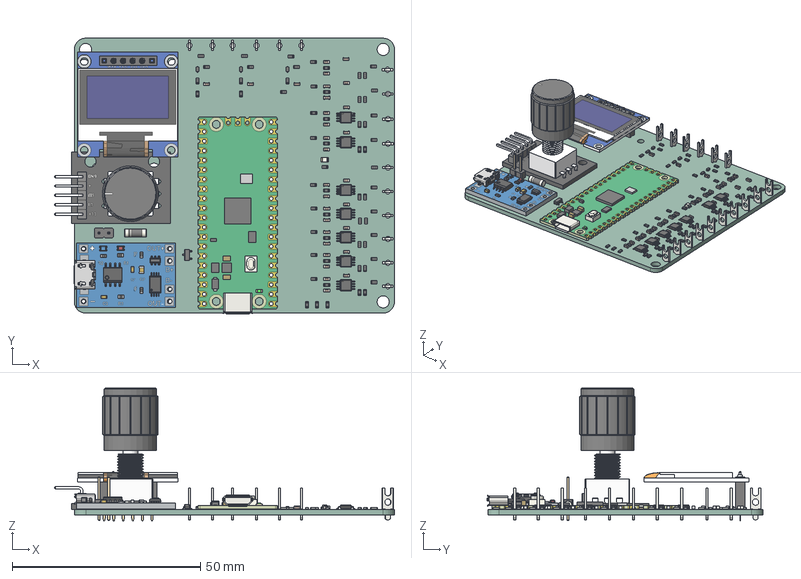
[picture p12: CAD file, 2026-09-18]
hardware/3d_models/pico_ecg.step
90.3 x 73.2 x 35.2 mm
Pin_D1.4mm_L8.5mm_W2.8mm_FlatFork x 16
D_SOD-523 x 3
C_0603_1608Metric x 30
R_0603_1608Metric x 62
BODY_MUA08A x 7
LEAD_MUA08A x 56
RaspberryPi_Pico_Module_KiCad
D_MELF
Rotary Encoder - KY-040
PinSocket_1x06_P2.54mm_Vertical
OLED-128x64-0.96
PinHeader_1x02_P2.54mm_Vertical
bOARD
0603 Capacitor x 2
0603 Resistor x 5
0805 Capacitor
SOIC-8-150
LED - 0805 - Blue
LED - 0805 - Red
USB - Micro
tsop8
sot-23-6-2
LED_0805_2012Metric
SOT-23
pico_ecg_PCB

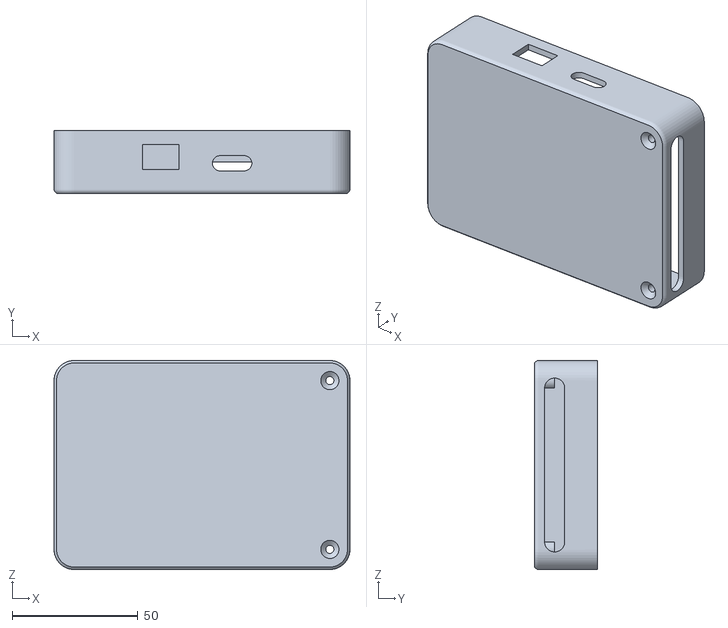
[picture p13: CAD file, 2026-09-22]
hardware/case/base.stl
117.5 x 25.0 x 83.0

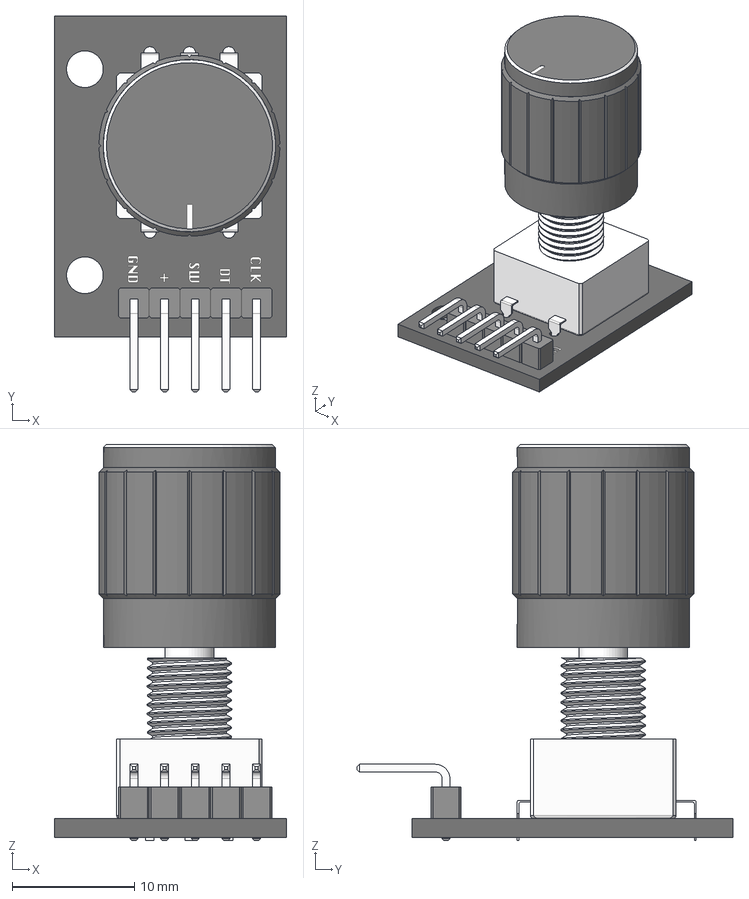
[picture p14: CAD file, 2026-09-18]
hardware/3d_models/Rotary Encoder - KY-040.step
19.0 x 30.8 x 32.4 mm

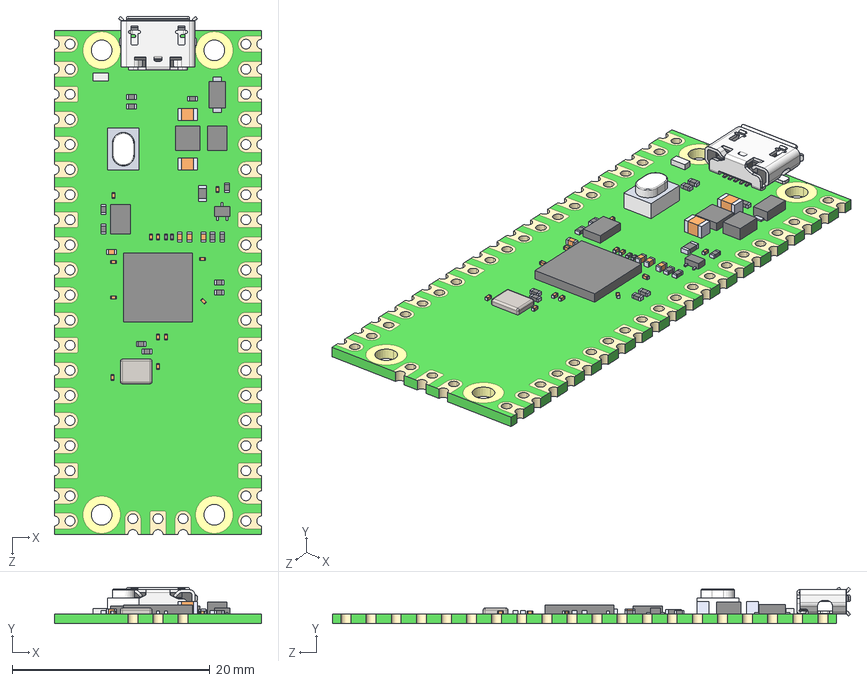
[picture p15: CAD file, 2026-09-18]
hardware/3d_models/Raspberry Pi Pico-R3.STEP
21.0 x 3.69 x 52.4 mm
PCB, Raspberry Pi Pico-R3
MicroUSB Port, Raspberry Pi Pico-R3
RP2040 Microcontroller, Raspberry Pi Pico-R3
SW1, Tact Switch, Raspberry Pi Pico-R3
D1, Diode, Schottky, Raspberry Pi Pico-R3
D2, QSME-C194, LED, Raspberry Pi Pico-R3
L1, Inductor, Raspberry Pi Pico-R3
U2, RT6150B-33GQW, Buck Boost Converter, Raspberry Pi Pico-R3
U3, W25Q16JVUXIQ, Serial NOR Flash 16 Mbit, Raspberry Pi Pico-R3
Q1, MOSFET, DMG1012T, Raspberry Pi Pico-R3
X1, X12M000000S096, 12 Mhz Crystal Resonator, Raspberry Pi Pico-R3
SMD Resistor, Configurable, Raspberry Pi Pico-R3_R1
SMD Resistor, Configurable, Raspberry Pi Pico-R3_R2
SMD Resistor, Configurable, Raspberry Pi Pico-R3_R3
SMD Resistor, Configurable, Raspberry Pi Pico-R3_R4
SMD Resistor, Configurable, Raspberry Pi Pico-R3_R5
SMD Resistor, Configurable, Raspberry Pi Pico-R3_R6
SMD Resistor, Configurable, Raspberry Pi Pico-R3_R7
SMD Resistor, Configurable, Raspberry Pi Pico-R3_R8
SMD Resistor, Configurable, Raspberry Pi Pico-R3_R9
SMD Resistor, Configurable, Raspberry Pi Pico-R3_R10
SMD Resistor, Configurable, Raspberry Pi Pico-R3_R11
SMD Resistor, Configurable, Raspberry Pi Pico-R3_R12
SMD Resistor, Configurable, Raspberry Pi Pico-R3_R13
SMD Resistor, Configurable, Raspberry Pi Pico-R3_R14
SMD Resistor, Configurable, Raspberry Pi Pico-R3_R15
SMD Capacitor, Configurable, Raspberry Pi Pico-R3_C1
SMD Capacitor, Configurable, Raspberry Pi Pico-R3_C2
SMD Capacitor, Configurable, Raspberry Pi Pico-R3_C3
SMD Capacitor, Configurable, Raspberry Pi Pico-R3_C4
SMD Capacitor, Configurable, Raspberry Pi Pico-R3_C5
SMD Capacitor, Configurable, Raspberry Pi Pico-R3_C6
SMD Capacitor, Configurable, Raspberry Pi Pico-R3_C7
SMD Capacitor, Configurable, Raspberry Pi Pico-R3_C8
SMD Capacitor, Configurable, Raspberry Pi Pico-R3_C9
SMD Capacitor, Configurable, Raspberry Pi Pico-R3_C10
SMD Capacitor, Configurable, Raspberry Pi Pico-R3_C11
SMD Capacitor, Configurable, Raspberry Pi Pico-R3_C12
SMD Capacitor, Configurable, Raspberry Pi Pico-R3_C13
SMD Capacitor, Configurable, Raspberry Pi Pico-R3_C14
SMD Capacitor, Configurable, Raspberry Pi Pico-R3_C15
SMD Capacitor, Configurable, Raspberry Pi Pico-R3_C16
SMD Capacitor, Configurable, Raspberry Pi Pico-R3_C17
SMD Capacitor, Configurable, Raspberry Pi Pico-R3_C18

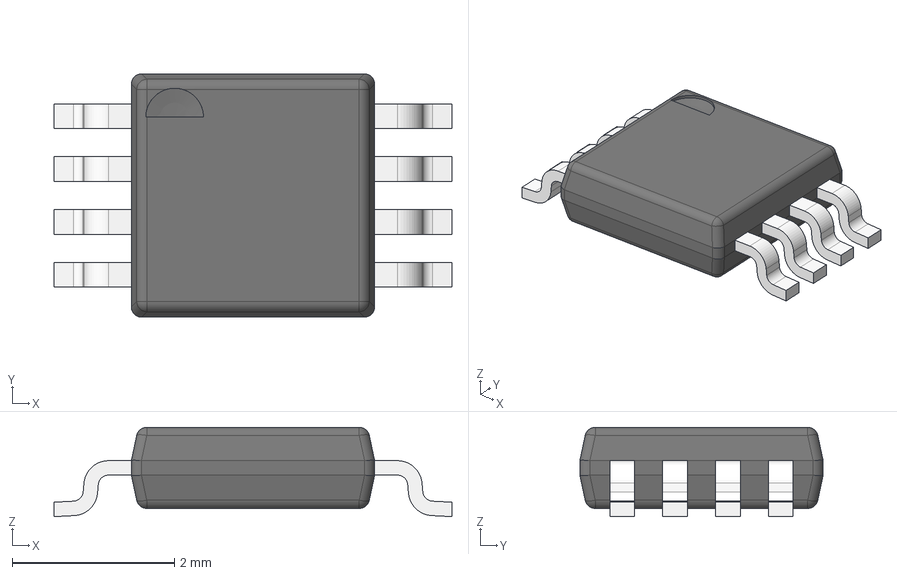
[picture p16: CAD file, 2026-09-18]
hardware/3d_models/DGK0008A.stp
4.90 x 3.00 x 1.10 mm
BODY_MUA08A
LEAD_MUA08A x 8

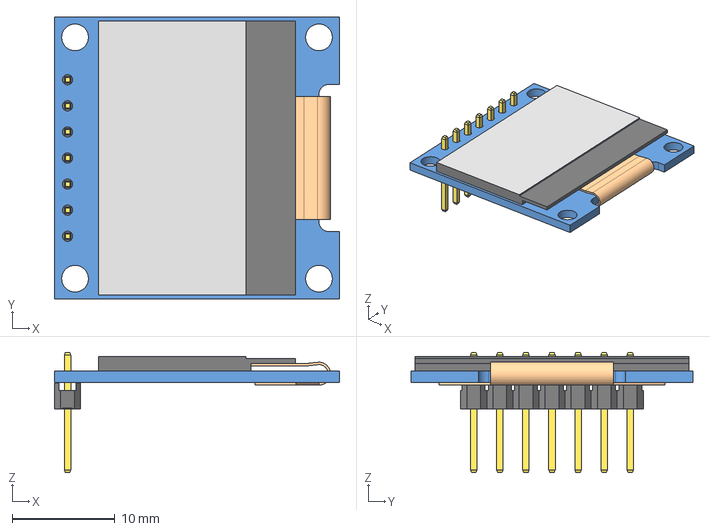
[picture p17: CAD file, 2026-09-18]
hardware/3d_models/OLED 0.96_ V2.0.step
27.8 x 27.5 x 11.7 mm
LCD
Flex

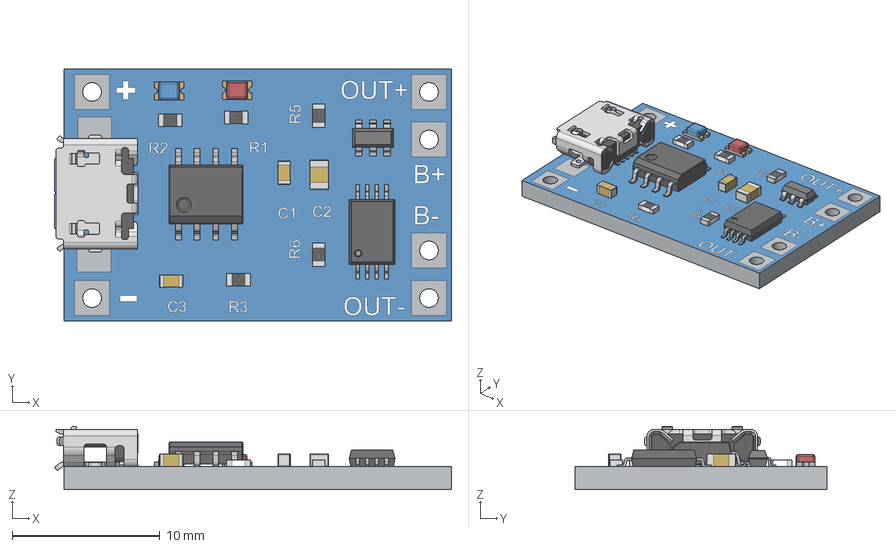
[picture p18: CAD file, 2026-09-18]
hardware/3d_models/Lipo Charger - With Load Protection.stp
26.9 x 17.1 x 4.28 mm
bOARD
0603 Capacitor x 2
0603 Resistor x 5
0805 Capacitor
SOIC-8-150
LED - 0805 - Blue
LED - 0805 - Red
USB - Micro
tsop8
sot-23-6-2

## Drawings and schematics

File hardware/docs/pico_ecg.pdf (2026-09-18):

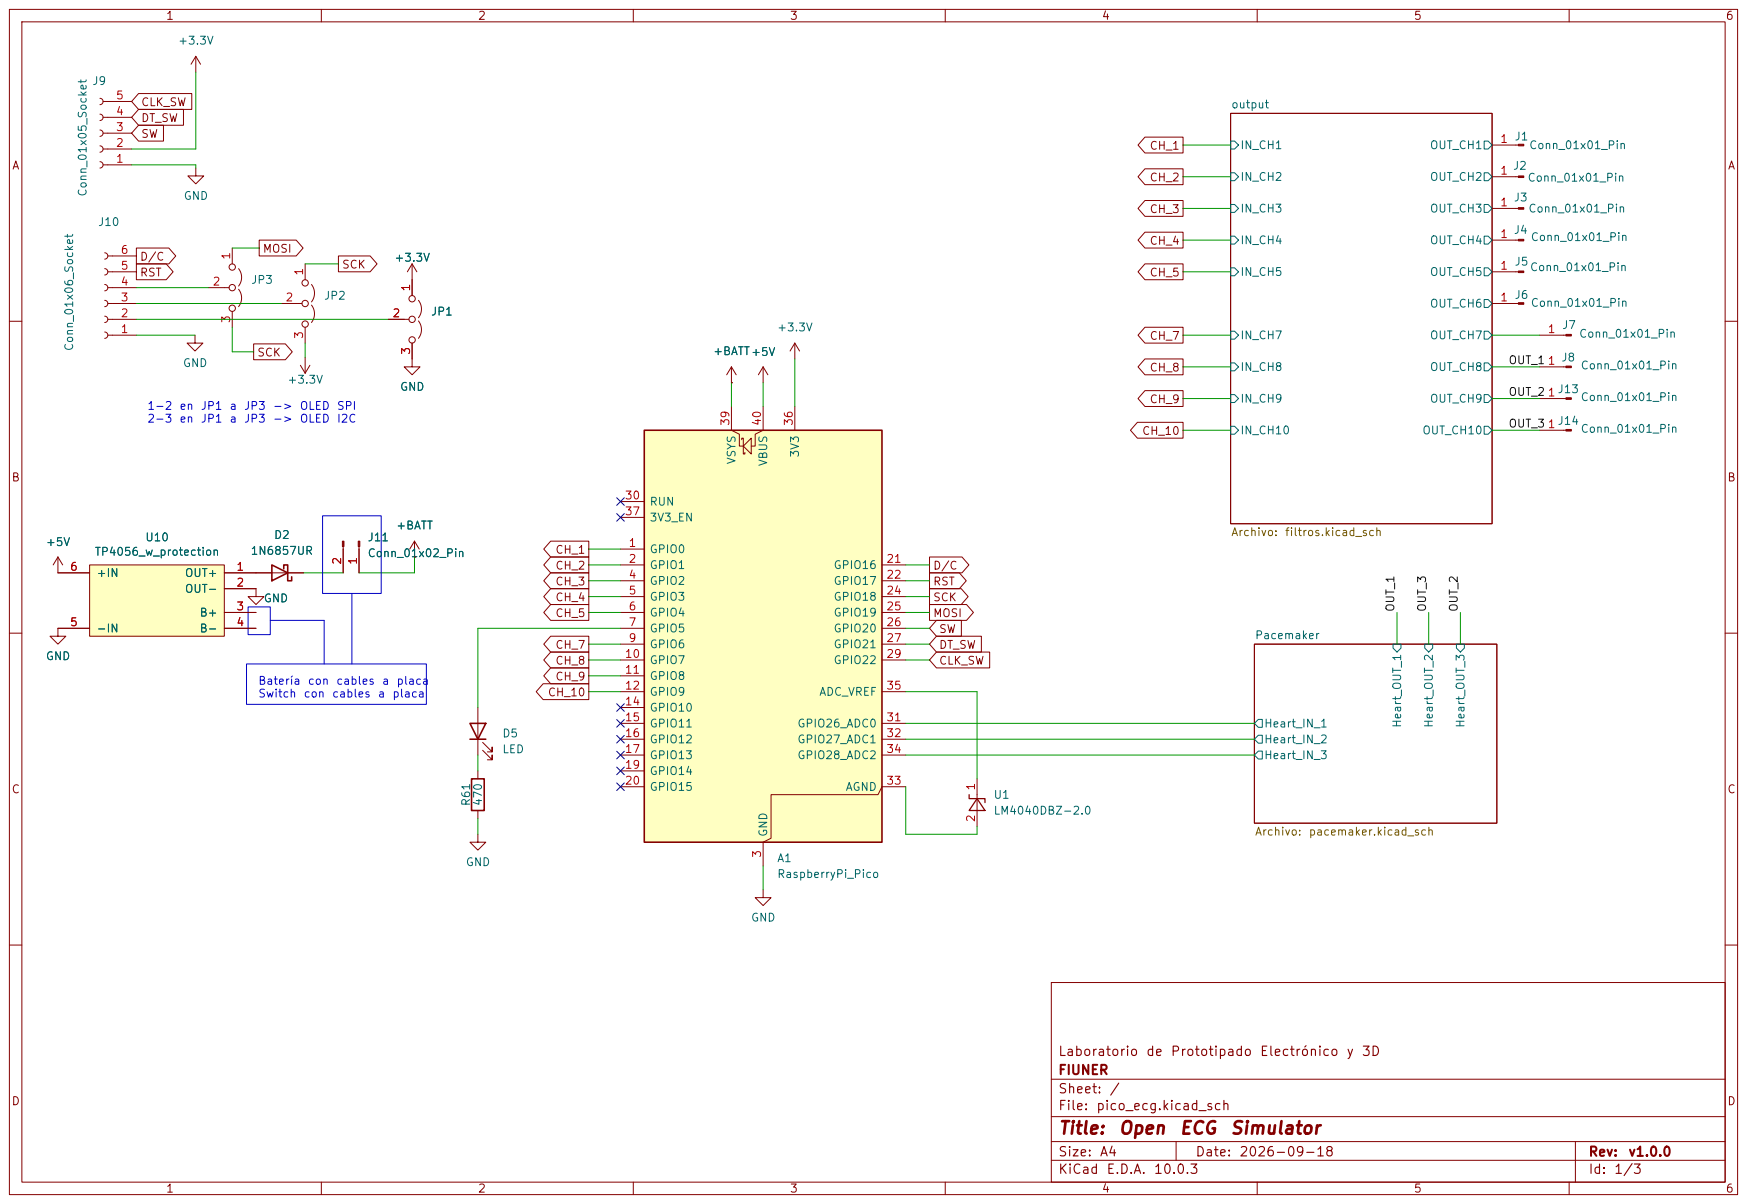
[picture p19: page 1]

1-2 en JP1 a JP3 -> OLED SPI 2-3 en JP1 a JP3 -> OLED I2C

Batería con cables a placa Switch con cables a placa

Laboratorio de Prototipado Electrónico y 3D
FIUNER
Sheet: /
File: pico_ecg.kicad_sch
Title: Open ECG Simulator

Size: A4 | Rev: v1.0.0
KiCad E.D.A. 10.0.3 | Id: 1/3

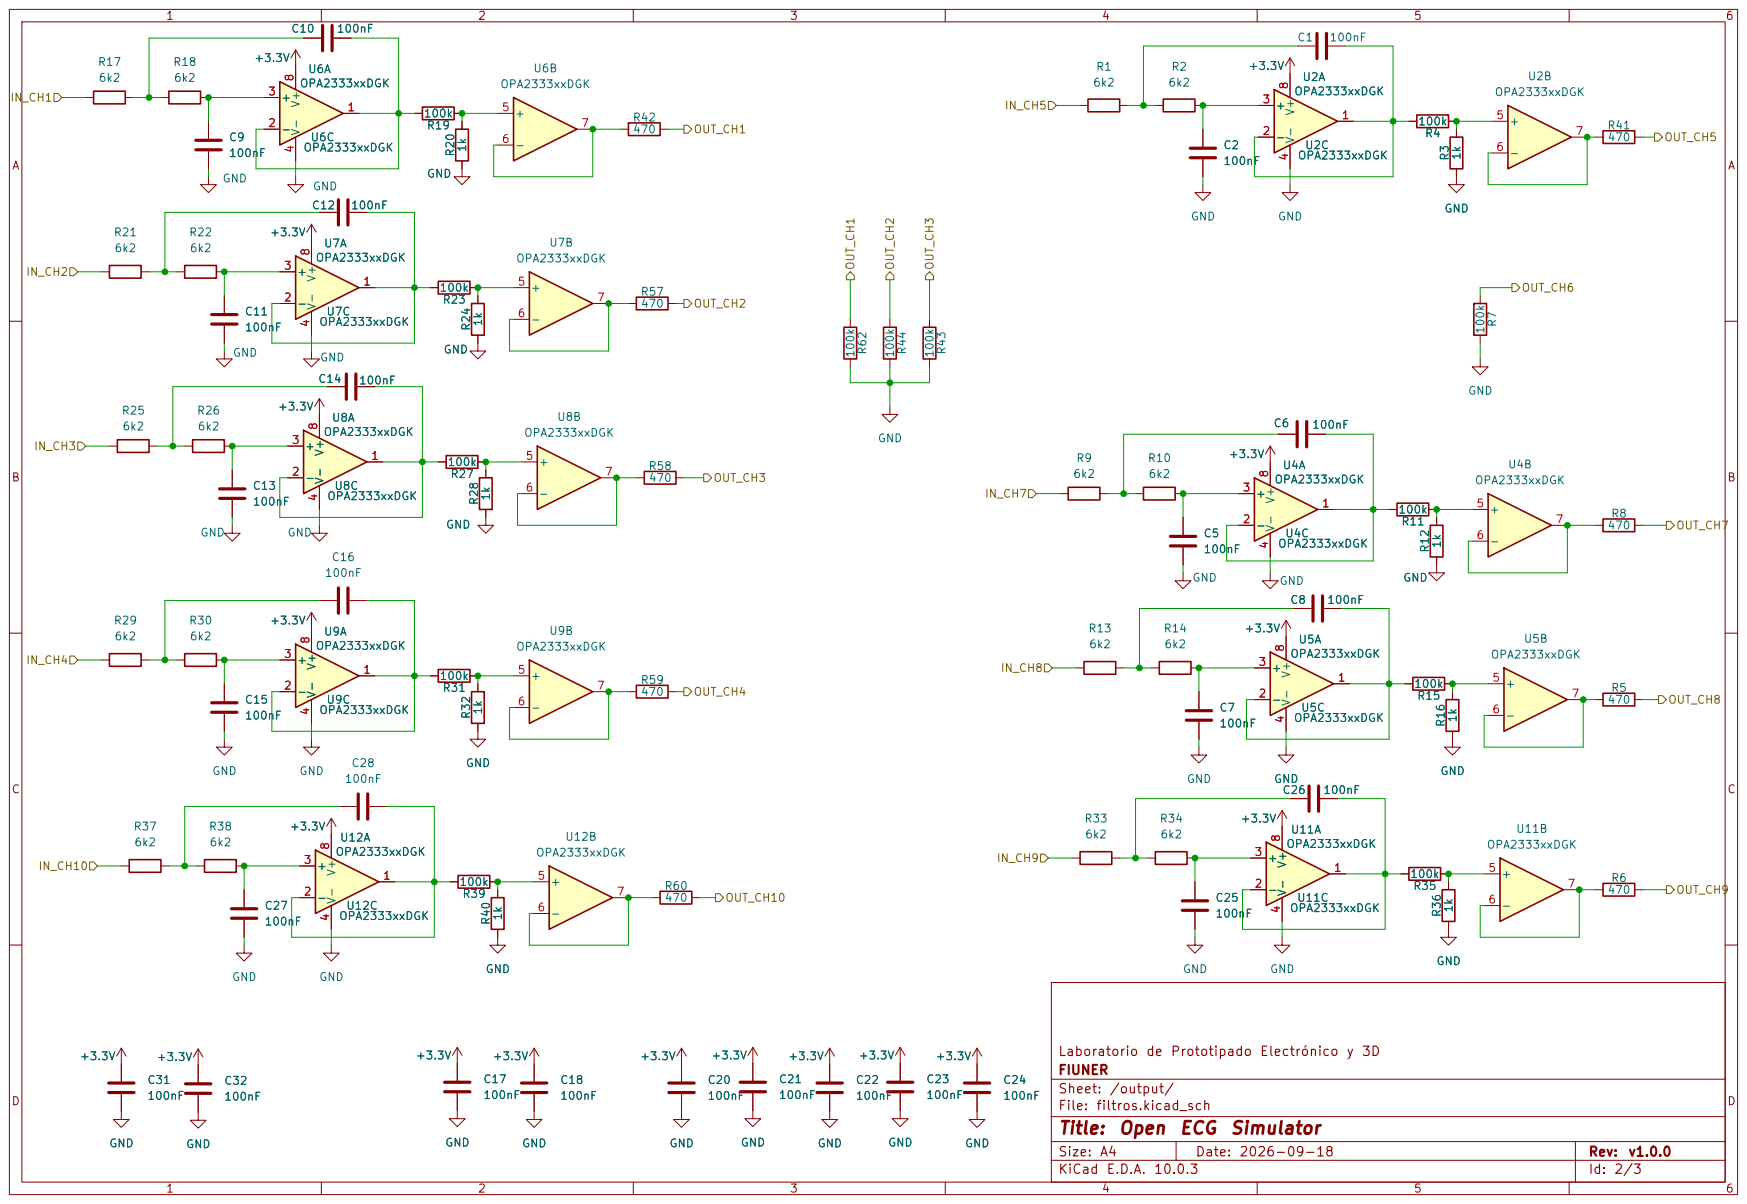
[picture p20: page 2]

FIUNER
Sheet: /output/
File: filtros.kicad_sch
Title: Open ECG Simulator

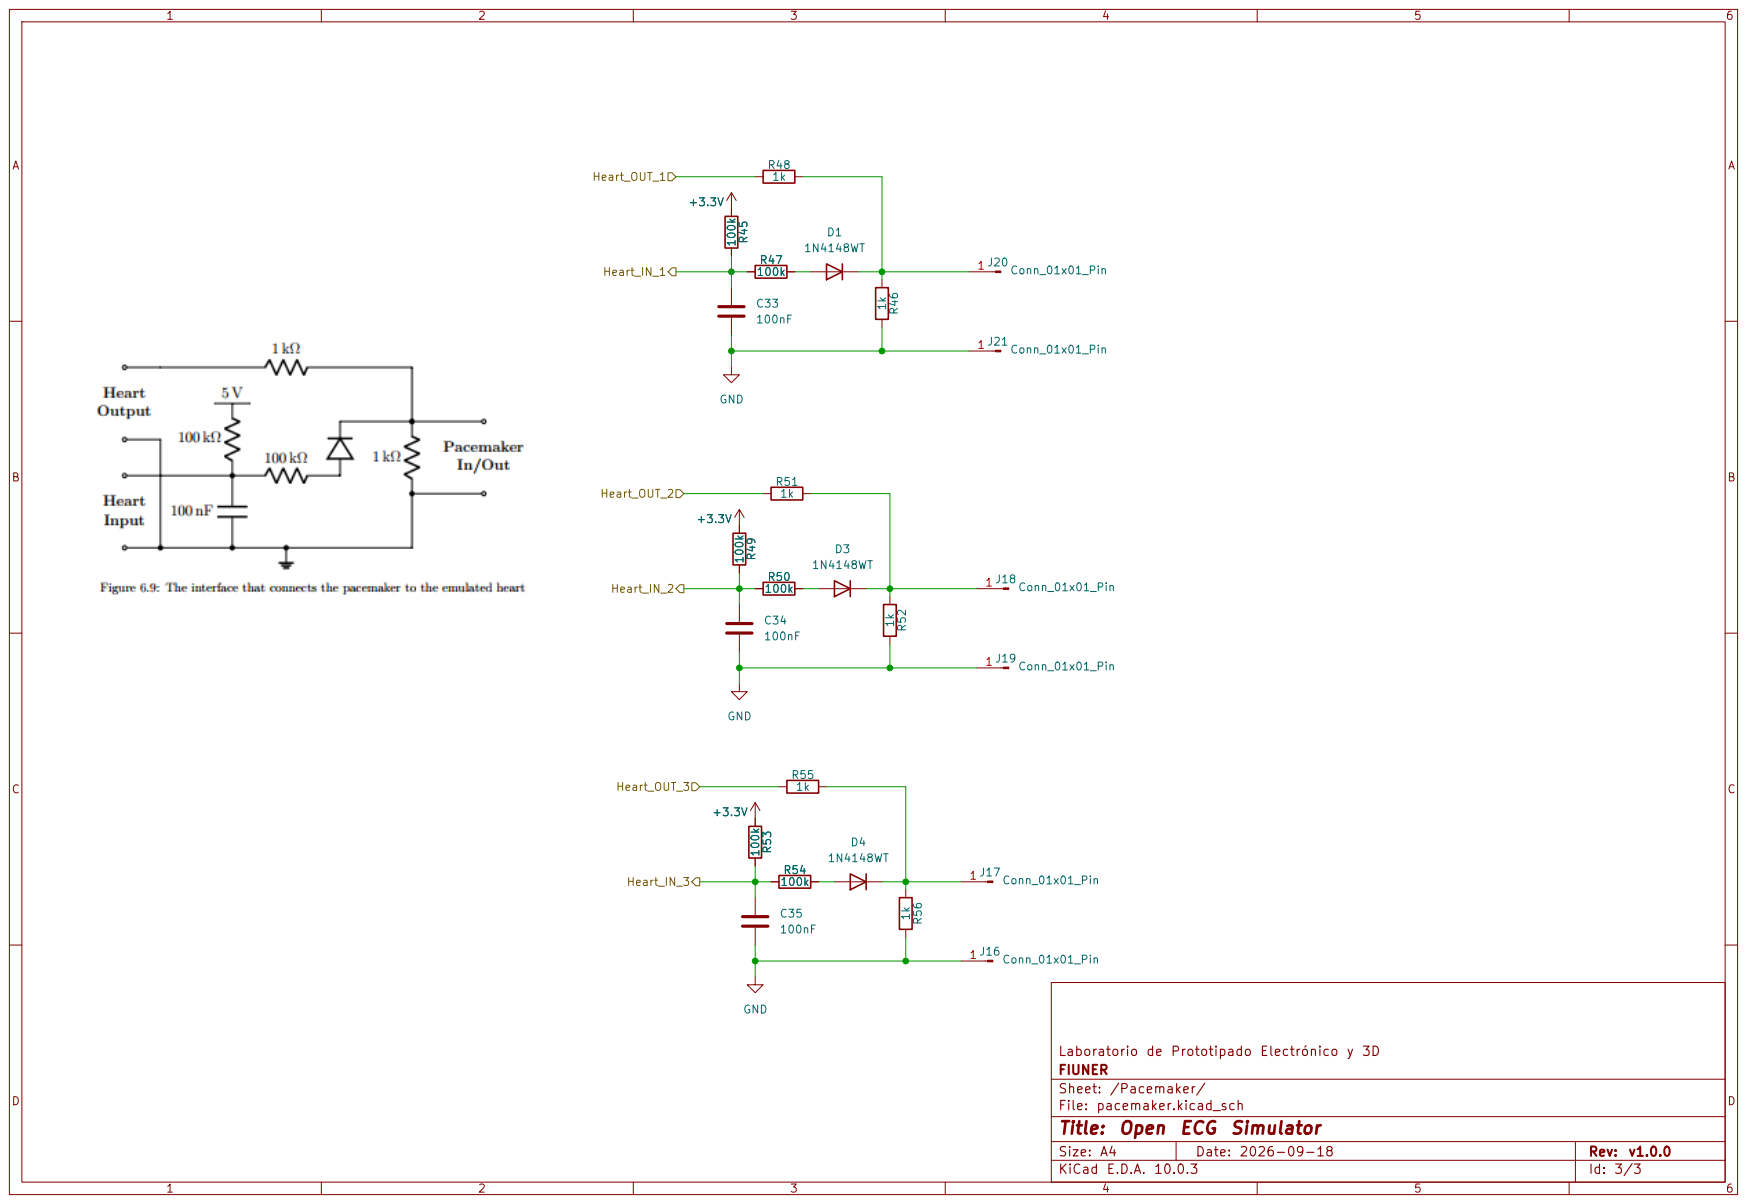
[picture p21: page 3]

FIUNER
Sheet: /Pacemaker/
File: pacemaker.kicad_sch
Title: Open ECG Simulator

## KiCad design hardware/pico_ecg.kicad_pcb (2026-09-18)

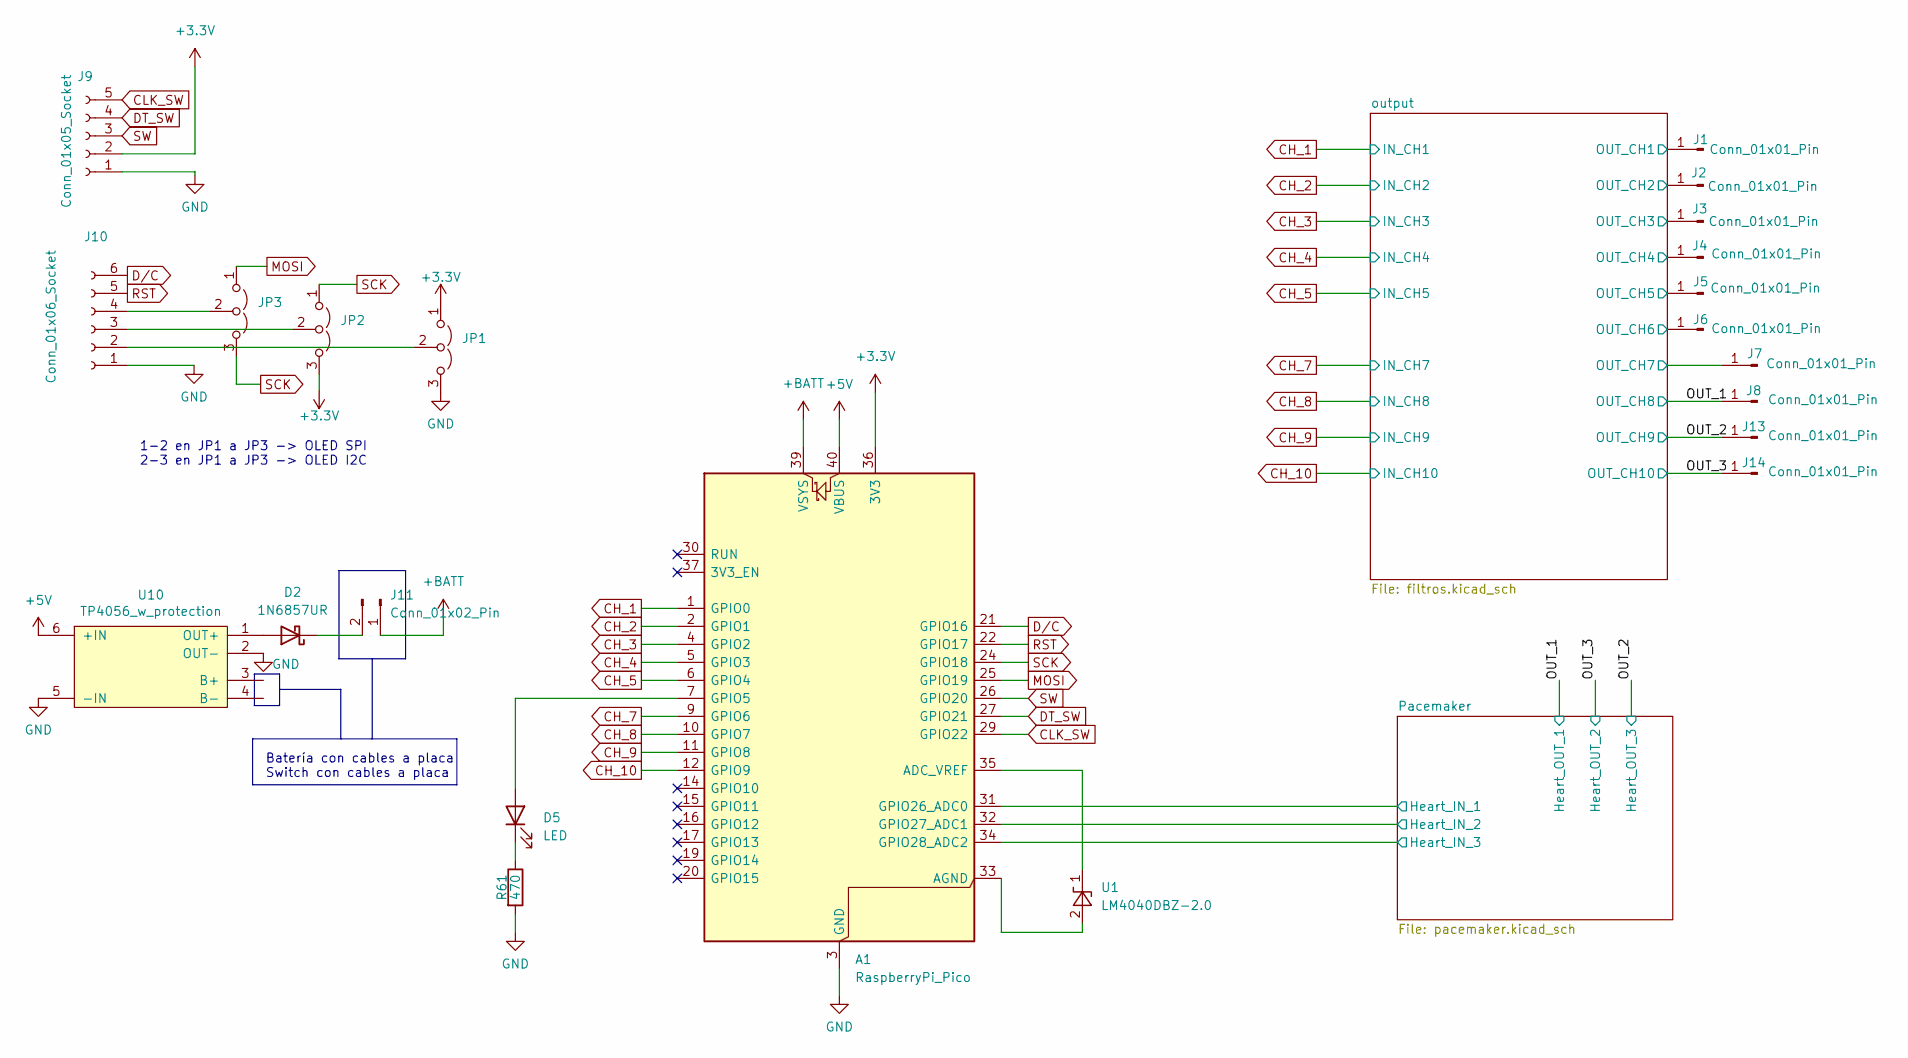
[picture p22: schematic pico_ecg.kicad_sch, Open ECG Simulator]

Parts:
A1: RaspberryPi_Pico; RaspberryPi_Pico_Common_Unspecified; Manufacturer PN SC1631
D2: 1N6857UR; D_MELF
D5: LED; LED_0805_2012Metric; Manufacturer PN 160-1427-1-ND
J1, J2, J3, J4, J5, J6, J7, J8, J13, J14: Conn_01x01_Pin; Pin_D1.4mm_L8.5mm_W2.8mm_FlatFork
J9: Conn_01x05_Socket; PinSocket_1x05_P2.54mm_Vertical
J10: Conn_01x06_Socket; PinSocket_1x06_P2.54mm_Vertical
J11: Conn_01x02_Pin; PinHeader_1x02_P2.54mm_Vertical
JP1, JP2, JP3: Jumper_3_Open; SolderJumper-3_P1.3mm_Open_RoundedPad1.0x1.5mm
R61: 470; R_0603_1608Metric_Pad0.98x0.95mm_HandSolder; Manufacturer PN RC0603JR-07470RL
U1: LM4040DBZ-2.0; SOT-23; Manufacturer PN LM4040CIM3-2.0/NOPB
U10: TP4056_w_protection

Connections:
+3.3V: A1.36 (3V3), J9.2, JP1.1 (A), JP2.3 (B); also elsewhere on the board
+5V: A1.40 (VBUS), U10.6 (+IN)
+BATT: A1.39 (VSYS), J11.1
/OUT_1: J8.1; also elsewhere on the board
/OUT_2: J13.1; also elsewhere on the board
/OUT_3: J14.1; also elsewhere on the board
/Pacemaker/Heart_IN_1: A1.31 (GPIO26_ADC0); also elsewhere on the board
/Pacemaker/Heart_IN_2: A1.32 (GPIO27_ADC1); also elsewhere on the board
/Pacemaker/Heart_IN_3: A1.34 (GPIO28_ADC2); also elsewhere on the board
/output/OUT_CH1: J1.1; also elsewhere on the board
/output/OUT_CH2: J2.1; also elsewhere on the board
/output/OUT_CH3: J3.1; also elsewhere on the board
/output/OUT_CH4: J4.1; also elsewhere on the board
/output/OUT_CH5: J5.1; also elsewhere on the board
/output/OUT_CH6: J6.1; also elsewhere on the board
/output/OUT_CH7: J7.1; also elsewhere on the board
CH_1: A1.1 (GPIO0); also elsewhere on the board
CH_2: A1.2 (GPIO1); also elsewhere on the board
CH_3: A1.4 (GPIO2); also elsewhere on the board
CH_4: A1.5 (GPIO3); also elsewhere on the board
CH_5: A1.6 (GPIO4); also elsewhere on the board
CH_7: A1.9 (GPIO6); also elsewhere on the board
CH_8: A1.10 (GPIO7); also elsewhere on the board
CH_9: A1.11 (GPIO8); also elsewhere on the board
CH_10: A1.12 (GPIO9); also elsewhere on the board
CLK_SW: A1.29 (GPIO22), J9.5
DT_SW: A1.27 (GPIO21), J9.4
D/C: A1.21 (GPIO16), J10.6
GND: A1.3 (GND), A1.8 (GND), A1.13 (GND), A1.18 (GND), A1.23 (GND), A1.28 (GND), A1.38 (GND), J9.1, J10.1, JP1.3 (B), R61.2, U10.2 (OUT-), U10.5 (-IN); also elsewhere on the board
MOSI: A1.25 (GPIO19), JP3.1 (A)
unnamed: A1.35 (ADC_VREF), U1.1 (K)
unnamed: A1.33 (AGND), U1.2 (A)
unnamed: A1.7 (GPIO5), D5.2 (A)
unnamed: D2.2 (A), U10.1 (OUT+)
unnamed: D2.1 (K), J11.2
unnamed: D5.1 (K), R61.1
unnamed: J10.2, JP1.2 (C)
unnamed: J10.3, JP2.2 (C)
unnamed: J10.4, JP3.2 (C)
RST: A1.22 (GPIO17), J10.5
SCK: A1.24 (GPIO18), JP2.1 (A), JP3.3 (B)
SW: A1.26 (GPIO20), J9.3

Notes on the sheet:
1-2 en JP1 a JP3 -> OLED SPI 2-3 en JP1 a JP3 -> OLED I2C
Batería con cables a placa Switch con cables a placa

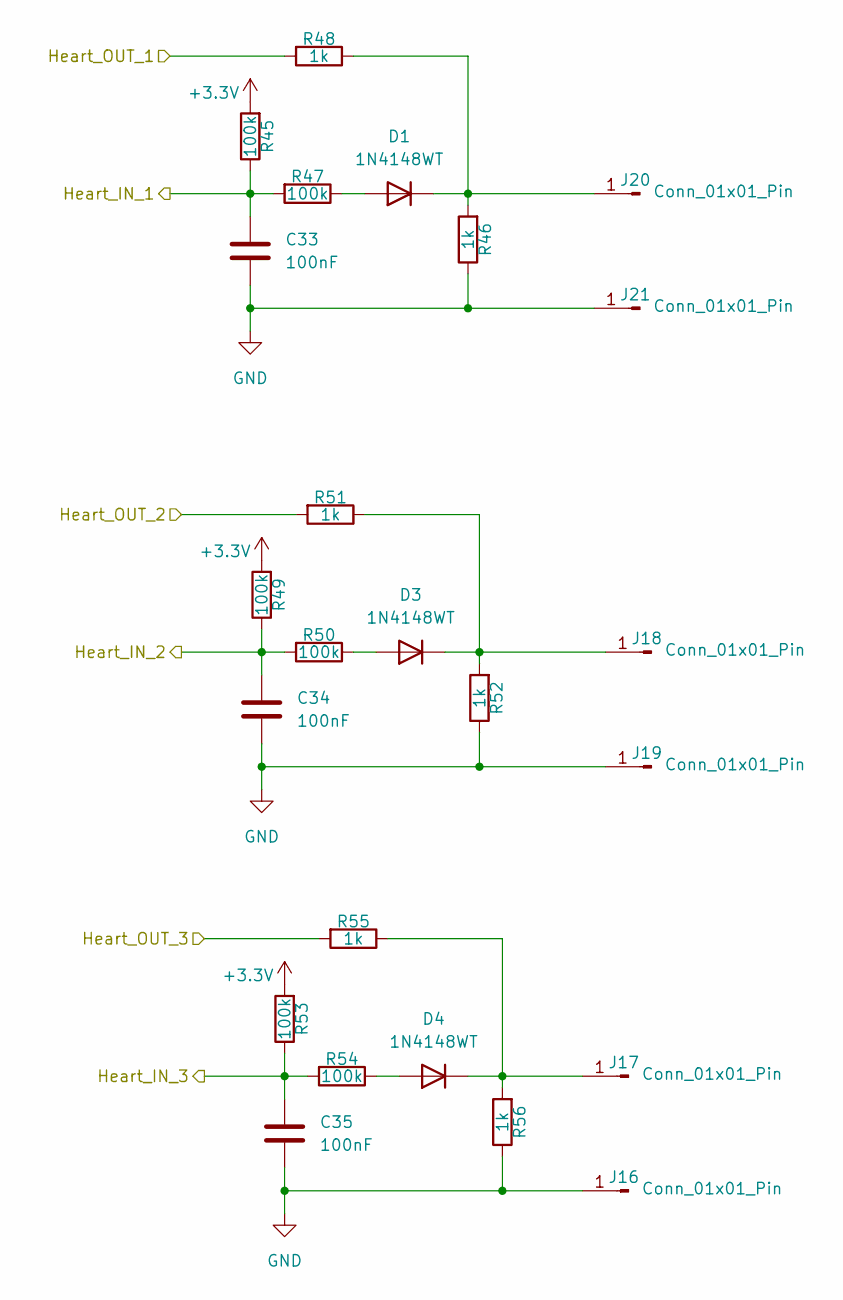
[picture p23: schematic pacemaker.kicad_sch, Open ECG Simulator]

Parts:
C33, C34, C35: 100nF; C_0603_1608Metric_Pad1.08x0.95mm_HandSolder; Manufacturer PN C0603C104K5RACTU
D1, D3, D4: 1N4148WT; D_SOD-523; Manufacturer PN 1N4148WT-7
J16, J17, J18, J19, J20, J21: Conn_01x01_Pin; Pin_D1.4mm_L8.5mm_W2.8mm_FlatFork
R45, R47, R49, R50, R53, R54: 100k; R_0603_1608Metric_Pad0.98x0.95mm_HandSolder; Manufacturer PN RC0603JR-07100KL
R46, R48, R51, R52, R55, R56: 1k; R_0603_1608Metric_Pad0.98x0.95mm_HandSolder; Manufacturer PN RC0603JR-071KL

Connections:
+3.3V: R45.2, R49.2, R53.2; also elsewhere on the board
/OUT_1: R48.2; also elsewhere on the board
/OUT_2: R55.2; also elsewhere on the board
/OUT_3: R51.2; also elsewhere on the board
/Pacemaker/Heart_IN_1: C33.2, R45.1, R47.2; also elsewhere on the board
/Pacemaker/Heart_IN_2: C34.2, R49.1, R50.2; also elsewhere on the board
/Pacemaker/Heart_IN_3: C35.2, R53.1, R54.2; also elsewhere on the board
GND: C33.1, C34.1, C35.1, J16.1, J19.1, J21.1, R46.1, R52.1, R56.1; also elsewhere on the board
unnamed: D1.2 (A), R47.1
unnamed: D1.1 (K), J20.1, R46.2, R48.1
unnamed: D3.2 (A), R50.1
unnamed: D3.1 (K), J18.1, R51.1, R52.2
unnamed: D4.2 (A), R54.1
unnamed: D4.1 (K), J17.1, R55.1, R56.2

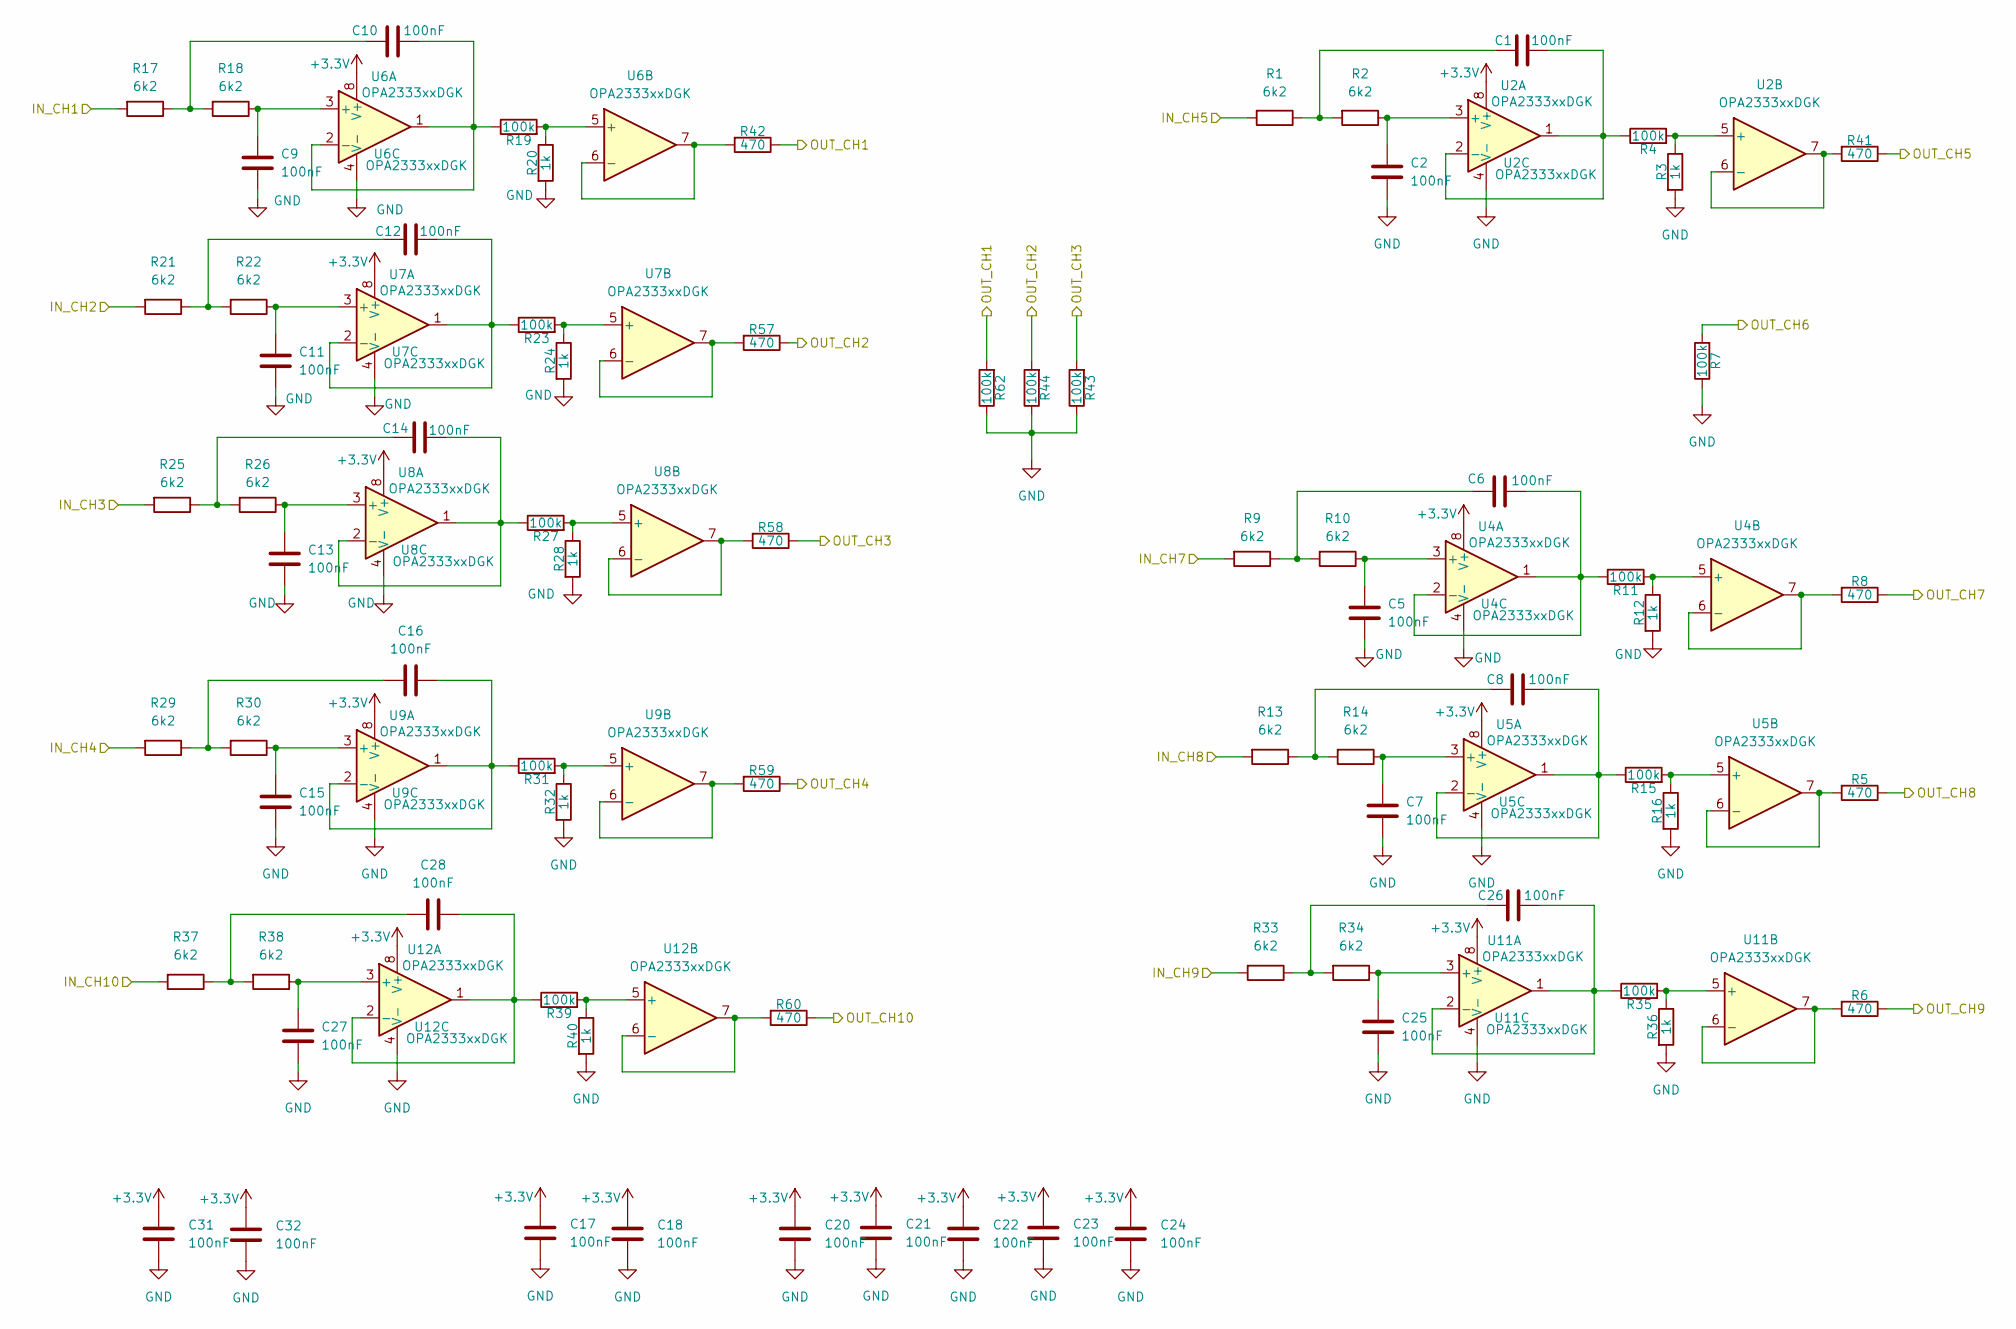
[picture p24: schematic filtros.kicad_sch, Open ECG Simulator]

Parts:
C1, C2, C5, C6, C7, C8, C9, C10, C11, C12, C13, C14, C15, C16, C17, C18, C20, C21, C22, C23, C24, C25, C26, C27, C28, C31, C32: 100nF; C_0603_1608Metric_Pad1.08x0.95mm_HandSolder; Manufacturer PN C0603C104K5RACTU
R1, R2, R9, R10, R13, R14, R17, R18, R21, R22, R25, R26, R29, R30, R33, R34, R37, R38: 6k2; R_0603_1608Metric_Pad0.98x0.95mm_HandSolder; Manufacturer PN RC0603JR-076K2L
R3, R12, R16, R20, R24, R28, R32, R36, R40: 1k; R_0603_1608Metric_Pad0.98x0.95mm_HandSolder; Manufacturer PN RC0603JR-071KL
R4, R7, R11, R15, R19, R23, R27, R31, R35, R39, R43, R44, R62: 100k; R_0603_1608Metric_Pad0.98x0.95mm_HandSolder; Manufacturer PN RC0603JR-07100KL
R5, R6, R8, R41, R42, R57, R58, R59, R60: 470; R_0603_1608Metric_Pad0.98x0.95mm_HandSolder; Manufacturer PN RC0603JR-07470RL
U2, U4, U5, U6, U7, U8, U9, U11, U12: OPA2333xxDGK; DGK8-L; Manufacturer PN OPA2333AIDGKR

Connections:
+3.3V: C17.2, C18.2, C20.2, C21.2, C22.2, C23.2, C24.2, C31.2, C32.2, U2.8 (V+), U4.8 (V+), U5.8 (V+), U6.8 (V+), U7.8 (V+), U8.8 (V+), U9.8 (V+), U11.8 (V+), U12.8 (V+); also elsewhere on the board
/OUT_1: R5.1; also elsewhere on the board
/OUT_2: R6.1; also elsewhere on the board
/OUT_3: R60.1; also elsewhere on the board
/output/OUT_CH1: R42.1, R62.2; also elsewhere on the board
/output/OUT_CH2: R44.2, R57.1; also elsewhere on the board
/output/OUT_CH3: R43.2, R58.1; also elsewhere on the board
/output/OUT_CH4: R59.1; also elsewhere on the board
/output/OUT_CH5: R41.1; also elsewhere on the board
/output/OUT_CH6: R7.2; also elsewhere on the board
/output/OUT_CH7: R8.1; also elsewhere on the board
CH_1: R17.2; also elsewhere on the board
CH_2: R21.2; also elsewhere on the board
CH_3: R25.2; also elsewhere on the board
CH_4: R29.2; also elsewhere on the board
CH_5: R1.2; also elsewhere on the board
CH_7: R9.2; also elsewhere on the board
CH_8: R13.2; also elsewhere on the board
CH_9: R33.2; also elsewhere on the board
CH_10: R37.2; also elsewhere on the board
GND: C2.2, C5.2, C7.2, C9.2, C11.2, C13.2, C15.2, C17.1, C18.1, C20.1, C21.1, C22.1, C23.1, C24.1, C25.2, C27.2, C31.1, C32.1, R3.2, R7.1, R12.2, R16.2, R20.2, R24.2, R28.2, R32.2, R36.2, R40.2, R43.1, R44.1, R62.1, U2.4 (V-), U4.4 (V-), U5.4 (V-), U6.4 (V-), U7.4 (V-), U8.4 (V-), U9.4 (V-), U11.4 (V-), U12.4 (V-); also elsewhere on the board
unnamed: C1.1, R1.1, R2.2
unnamed: C6.1, R9.1, R10.2
unnamed: C8.1, R13.1, R14.2
unnamed: C10.1, R17.1, R18.2
unnamed: C12.1, R21.1, R22.2
unnamed: C14.1, R25.1, R26.2
unnamed: C16.1, R29.1, R30.2
unnamed: C26.1, R33.1, R34.2
unnamed: C28.1, R37.1, R38.2
unnamed: C2.1, R2.1, U2.3 (+)
unnamed: C1.2, R4.1, U2.1, U2.2 (-)
unnamed: R3.1, R4.2, U2.5 (+)
unnamed: R41.2, U2.6 (-), U2.7
unnamed: C5.1, R10.1, U4.3 (+)
unnamed: C6.2, R11.1, U4.1, U4.2 (-)
unnamed: R11.2, R12.1, U4.5 (+)
unnamed: R8.2, U4.6 (-), U4.7
unnamed: C7.1, R14.1, U5.3 (+)
unnamed: C8.2, R15.1, U5.1, U5.2 (-)
unnamed: R15.2, R16.1, U5.5 (+)
unnamed: R5.2, U5.6 (-), U5.7
unnamed: C9.1, R18.1, U6.3 (+)
unnamed: C10.2, R19.1, U6.1, U6.2 (-)
unnamed: R19.2, R20.1, U6.5 (+)
unnamed: R42.2, U6.6 (-), U6.7
unnamed: C11.1, R22.1, U7.3 (+)
unnamed: C12.2, R23.1, U7.1, U7.2 (-)
unnamed: R23.2, R24.1, U7.5 (+)
unnamed: R57.2, U7.6 (-), U7.7
unnamed: C13.1, R26.1, U8.3 (+)
unnamed: C14.2, R27.1, U8.1, U8.2 (-)
unnamed: R27.2, R28.1, U8.5 (+)
unnamed: R58.2, U8.6 (-), U8.7
unnamed: C15.1, R30.1, U9.3 (+)
unnamed: C16.2, R31.1, U9.1, U9.2 (-)
unnamed: R31.2, R32.1, U9.5 (+)
unnamed: R59.2, U9.6 (-), U9.7
unnamed: C25.1, R34.1, U11.3 (+)
unnamed: C26.2, R35.1, U11.1, U11.2 (-)
unnamed: R35.2, R36.1, U11.5 (+)
unnamed: R6.2, U11.6 (-), U11.7
unnamed: C27.1, R38.1, U12.3 (+)
unnamed: C28.2, R39.1, U12.1, U12.2 (-)
unnamed: R39.2, R40.1, U12.5 (+)
unnamed: R60.2, U12.6 (-), U12.7

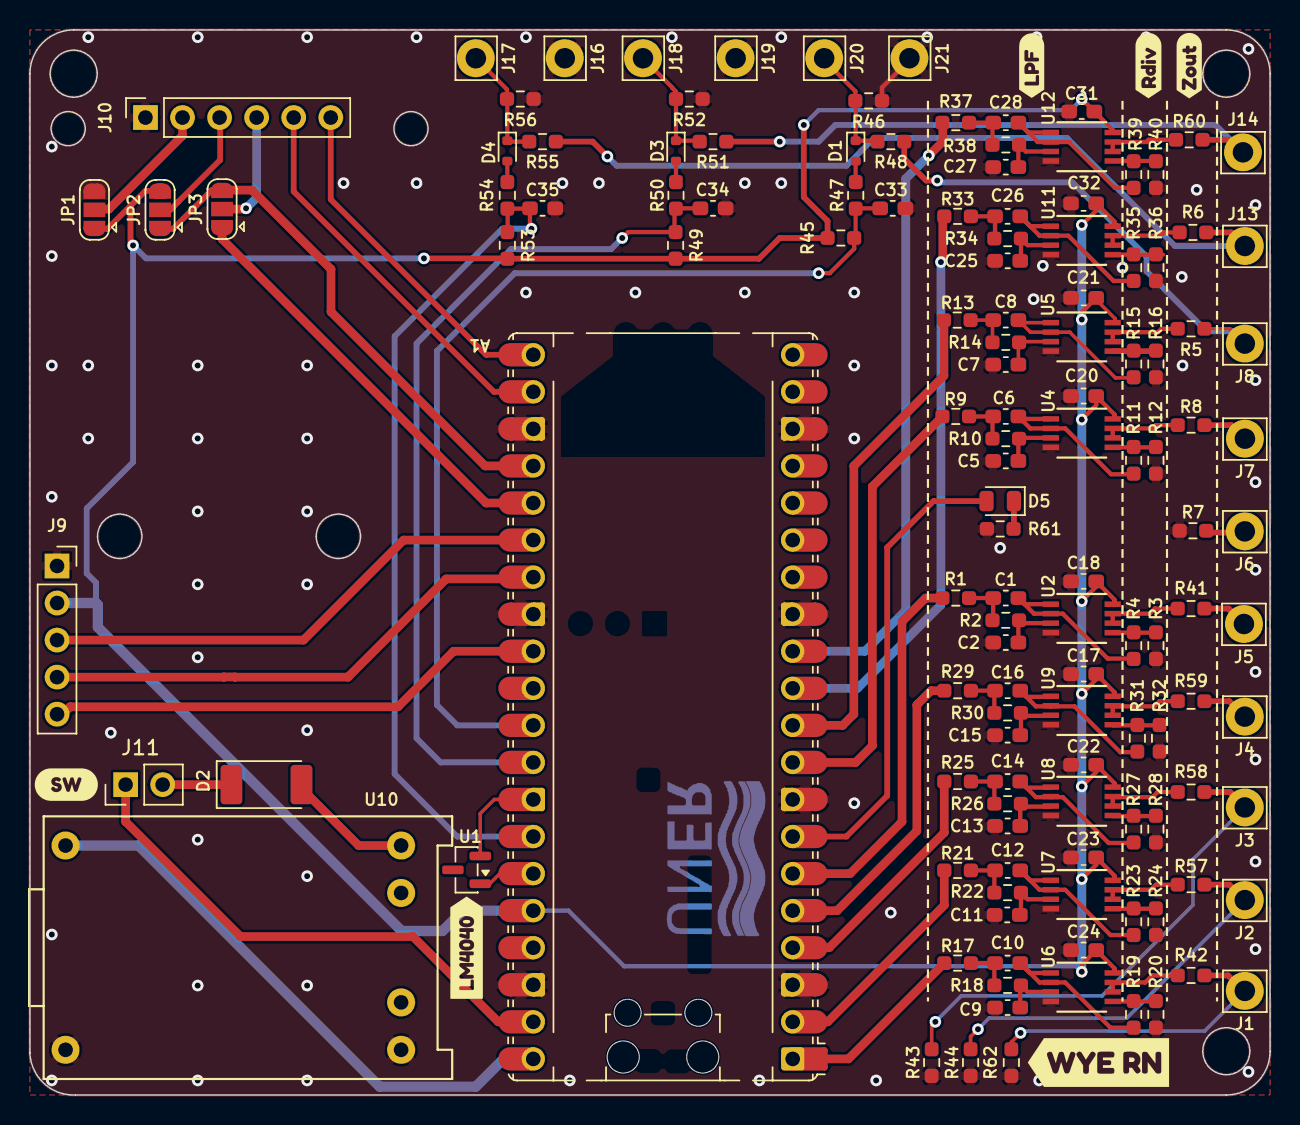
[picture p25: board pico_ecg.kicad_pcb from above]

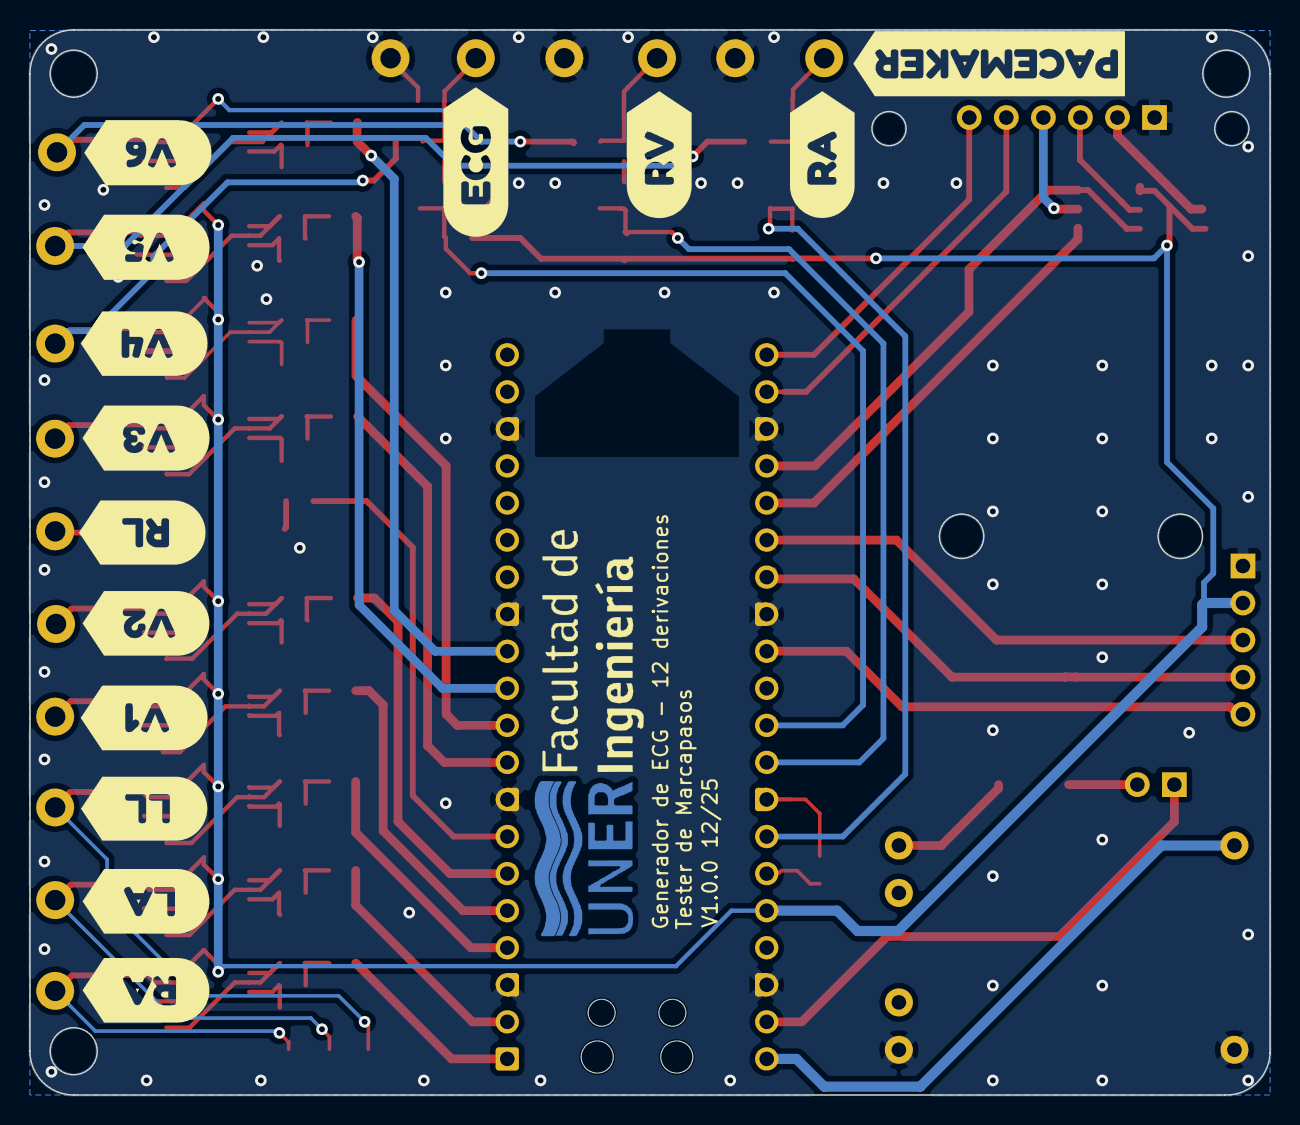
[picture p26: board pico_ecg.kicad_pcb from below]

Board: 2 copper layers, 85.0 x 73.0 mm, 151 parts (14 on the bottom side), 93 nets.

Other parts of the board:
kibuzzard-695407C8: G***; kibuzzard-695407C8
kibuzzard-695407DC: G***; kibuzzard-695407DC
kibuzzard-695407F6: G***; kibuzzard-695407F6
kibuzzard-695407FF: G***; kibuzzard-695407FF
kibuzzard-695409B2: G***; kibuzzard-695409B2
kibuzzard-695409D3: G***; kibuzzard-695409D3
kibuzzard-695409F9: G***; kibuzzard-695409F9
kibuzzard-6954080E: G***; kibuzzard-6954080E
kibuzzard-6954081B: G***; kibuzzard-6954081B
kibuzzard-6954082B: G***; kibuzzard-6954082B
kibuzzard-6954083E: G***; kibuzzard-6954083E
kibuzzard-6954084A: G***; kibuzzard-6954084A
kibuzzard-69540806: G***; kibuzzard-69540806
kibuzzard-69540813: G***; kibuzzard-69540813
kibuzzard-69540823: G***; kibuzzard-69540823
kibuzzard-69540831: G***; kibuzzard-69540831
kibuzzard-69540844: G***; kibuzzard-69540844
kibuzzard-69540856: G***; kibuzzard-69540856
kibuzzard-69540869: G***; kibuzzard-69540869
kibuzzard-69540875: G***; kibuzzard-69540875

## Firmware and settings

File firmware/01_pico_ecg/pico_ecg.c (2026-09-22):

#include <stdio.h>
#include <string.h>
#include "pico/stdlib.h"
#include "pico/stdio_usb.h"
#include "pico/multicore.h"
#include "hardware/gpio.h"
#include "interface.h"
#include "menu.h"
#include "cli.h"
#include "signal_gen.h"
#include "terminal_control.h"

int main(void) {
    // Initialize GPIO FIRST before anything else
    gpio_init(5); // LED pin
    gpio_set_dir(5, GPIO_OUT);
    
    // Blink LED to show we're alive
    for (int i = 0; i < 5; i++) {
        gpio_put(5, 1);
        sleep_ms(100);
        gpio_put(5, 0);
        sleep_ms(100);
    }
    
    // Now init stdio
    stdio_init_all();
    stdio_set_translate_crlf(&stdio_usb, false);
    sleep_ms(500);

    printf("\n\n=== ECG Monitor Starting ===\n");
    fflush(stdout);
    
    printf("Initializing interface...\n");
    fflush(stdout);
    interface_init();
    interface_splash_animation();
    interface_show_info_screen();
    sleep_ms(100);
    
    printf("Initializing signal generator...\n");
    fflush(stdout);
    signal_gen_init();
    signal_gen_start();
    sleep_ms(100);
    
    printf("Interface initialized\n");
    fflush(stdout);
    sleep_ms(100);
    
    printf("Initializing menu...\n");
    fflush(stdout);
    
    // Blink LED to indicate menu init starting
    gpio_put(5, 1);
    sleep_ms(50);
    gpio_put(5, 0);
    
    menu_init();
    terminal_control_init();
    
    // Another blink to indicate menu init done
    gpio_put(5, 1);
    sleep_ms(50);
    gpio_put(5, 0);
    
    sleep_ms(100);

    printf("Launching signal generator on core 1...\n");
    fflush(stdout);
    multicore_launch_core1(signal_gen_core1_entry);
    sleep_ms(100);

    printf("Menu initialized - Starting main loop\n");
    fflush(stdout);
    
    // Main loop
    absolute_time_t next_blink = get_absolute_time();
    while (true) {
        // Heartbeat - Fast blink to show life
        /*if (absolute_time_diff_us(get_absolute_time(), next_blink) < 0) {
            interface_led_toggle();
            next_blink = make_timeout_time_ms(200);
        }*/

        // Process background tasks (buzzer, terminal blinking, encoder input, etc)
        interface_update();
        terminal_control_update();
        menu_process_input();

        if (!cli_is_streaming()) {
            menu_draw();
            sleep_ms(10);
        } else {
            static absolute_time_t last_draw = 0;
            if (absolute_time_diff_us(last_draw, get_absolute_time()) > 200000) { // 5 Hz refresh during streaming
                menu_draw();
                last_draw = get_absolute_time();
            }
            sleep_us(200);
        }
    }
}

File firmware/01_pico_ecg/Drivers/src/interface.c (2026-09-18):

#include "interface.h"
#include "animation.h"
#include "menu.h"
#include "tusb.h"
#include "pico/stdlib.h"
#include "hardware/gpio.h"
#include "hardware/spi.h"
#include "hardware/adc.h"

// ==================== Pin Definitions ====================
// OLED
#define SPI_PORT spi0
#define PIN_SCK  18
#define PIN_MOSI 19
#define PIN_DC   16
#define PIN_RST  17

// Encoder
#define PIN_ENCODER_DATA 21
#define PIN_ENCODER_CLK  22
#define PIN_ENCODER_BTN  20

// Peripherals
#define PIN_LED    5
#define PIN_BUZZER 15
#define PIN_ONBOARD_LED 25

// Battery and System
#define PIN_BATT_ADC 29  // ADC3
#define PIN_USB_DET  24

// ==================== Global Variables ====================
u8g2_t u8g2;

// Encoder State
static volatile int32_t encoder_count = 0;
static volatile int32_t last_encoder_read = 0;
static volatile uint8_t encoder_ab_last = 3; // Last quadrature state (CLK<<1)|DATA, 3 = both high (rest)
static volatile uint8_t encoder_cycle_edges = 0; // Transitions accumulated in current detent cycle
static volatile int8_t encoder_cycle_dir = 0;    // Running cycle direction (+1/-1), 0 = idle
static volatile bool button_pressed = false;
static volatile bool button_long_pressed = false;
static volatile bool button_released_event = false; // Internal for debouncing/release logic if needed
static uint32_t button_press_time = 0;

// ==================== Private Functions ====================
static void gpio_callback(uint gpio, uint32_t events);
static void encoder_process(void);

static uint8_t u8g2_gpio_and_delay_cb(u8x8_t *u8x8, uint8_t msg, uint8_t arg_int, void *arg_ptr) {
    switch(msg) {
        case U8X8_MSG_GPIO_DC:
            gpio_put(PIN_DC, arg_int);
            break;
        case U8X8_MSG_GPIO_RESET:
            gpio_put(PIN_RST, arg_int);
            break;
        case U8X8_MSG_DELAY_NANO:
            break;
        case U8X8_MSG_DELAY_10MICRO:
            sleep_us(10);
            break;
        case U8X8_MSG_DELAY_100NANO:
            break;
        case U8X8_MSG_DELAY_MILLI:
            sleep_ms(1);
            break;
        case U8X8_MSG_GPIO_AND_DELAY_INIT:
            break;
        default:
            return 0;
    }
    return 1;
}

static uint8_t u8g2_spi_byte_cb(u8x8_t *u8x8, uint8_t msg, uint8_t arg_int, void *arg_ptr) {
    switch(msg) {
        case U8X8_MSG_BYTE_SEND:
            spi_write_blocking(SPI_PORT, (uint8_t *)arg_ptr, arg_int);
            break;
        case U8X8_MSG_BYTE_INIT:
            break;
        case U8X8_MSG_BYTE_SET_DC:
            gpio_put(PIN_DC, arg_int);
            break;
        case U8X8_MSG_BYTE_START_TRANSFER:
            break;
        case U8X8_MSG_BYTE_END_TRANSFER:
            break;
        default:
            return 0;
    }
    return 1;
}

// ==================== Public Functions ====================

// Interface implementation starts from here (PWM init included below)

#include "hardware/pwm.h"
#include "hardware/clocks.h"

// ... (previous code)

void interface_init(void) {
    // --- LED ---
    gpio_init(PIN_LED);
    gpio_set_dir(PIN_LED, GPIO_OUT);
    gpio_put(PIN_LED, 0);

    // --- Buzzer (PWM) ---
    gpio_set_function(PIN_BUZZER, GPIO_FUNC_PWM);
    uint slice_num = pwm_gpio_to_slice_num(PIN_BUZZER);
    pwm_set_enabled(slice_num, false); // Disabled at start

    // --- Display ---
    spi_init(SPI_PORT, 2000000); 
    gpio_set_function(PIN_SCK, GPIO_FUNC_SPI);
    gpio_set_function(PIN_MOSI, GPIO_FUNC_SPI);
    
    gpio_init(PIN_DC);
    gpio_set_dir(PIN_DC, GPIO_OUT);
    gpio_put(PIN_DC, 0);

    gpio_init(PIN_RST);
    gpio_set_dir(PIN_RST, GPIO_OUT);
    gpio_put(PIN_RST, 1);

    // Initialize U8g2 (Try SH1106 if SSD1306 shows artifacts)
    u8g2_Setup_sh1106_128x64_noname_f(&u8g2, U8G2_R0, u8g2_spi_byte_cb, u8g2_gpio_and_delay_cb);
    u8g2_InitDisplay(&u8g2);
    u8g2_SetPowerSave(&u8g2, 0);
    u8g2_SetFont(&u8g2, u8g2_font_6x10_tf);
    
    // --- Encoder ---
    gpio_init(PIN_ENCODER_CLK);
    gpio_set_dir(PIN_ENCODER_CLK, GPIO_IN);
    gpio_pull_up(PIN_ENCODER_CLK);

    gpio_init(PIN_ENCODER_DATA);
    gpio_set_dir(PIN_ENCODER_DATA, GPIO_IN);
    gpio_pull_up(PIN_ENCODER_DATA);

    gpio_init(PIN_ENCODER_BTN);
    gpio_set_dir(PIN_ENCODER_BTN, GPIO_IN);
    gpio_pull_up(PIN_ENCODER_BTN);

    gpio_set_irq_enabled_with_callback(PIN_ENCODER_BTN, GPIO_IRQ_EDGE_FALL | GPIO_IRQ_EDGE_RISE, true, &gpio_callback);
    gpio_set_irq_enabled(PIN_ENCODER_CLK, GPIO_IRQ_EDGE_FALL | GPIO_IRQ_EDGE_RISE, true);
    gpio_set_irq_enabled(PIN_ENCODER_DATA, GPIO_IRQ_EDGE_FALL | GPIO_IRQ_EDGE_RISE, true);
    encoder_ab_last = (uint8_t)((gpio_get(PIN_ENCODER_CLK) << 1) | gpio_get(PIN_ENCODER_DATA));

    // --- Battery ADC ---
    adc_init();
    adc_gpio_init(PIN_BATT_ADC);
    
    // --- USB Detection ---
    // Onboard LED
    gpio_init(PIN_ONBOARD_LED);
    gpio_set_dir(PIN_ONBOARD_LED, GPIO_OUT);

    gpio_init(PIN_USB_DET);
    gpio_set_dir(PIN_USB_DET, GPIO_IN);
    gpio_pull_down(PIN_USB_DET); // Weak pull-down to ensure 0 when not connected
}

void interface_splash_animation(void) {
    for (int i = 0; i < ANIMATION_FRAMES; i++) {
        // Trigger melody notes at specific frames (Non-blocking requests)
        if (i == 0)  interface_buzzer_beep_nonblocking(440, 50); // A4
        if (i == 4)  interface_buzzer_beep_nonblocking(554, 50); // C#5
        if (i == 8)  interface_buzzer_beep_nonblocking(659, 50); // E5
        if (i == 12) interface_buzzer_beep_nonblocking(880, 80); // A5
        if (i == 14) interface_buzzer_beep_nonblocking(659, 50); // E5
        //if (i == 16) interface_buzzer_beep_nonblocking(880, 100); // A5
        u8g2_FirstPage(&u8g2);
        do {
            u8g2_SetBitmapMode(&u8g2, 1); // Transparent
            u8g2_DrawXBMP(&u8g2, 28, 0, 71, 64, epd_bitmap_allArray[i]);
        } while (u8g2_NextPage(&u8g2));
        
        // We must call interface_update if we want non-blocking beeps to work
        // during this blocking animation loop.
        interface_update();
        sleep_ms(50);
    }
}

void interface_show_info_screen(void) {
    u8g2_FirstPage(&u8g2);
    do {
        u8g2_SetFont(&u8g2, u8g2_font_9x15_tr);
        u8g2_DrawStr(&u8g2, 28, 15, "Open-ECG");
        u8g2_DrawStr(&u8g2, 23, 31, "Generator");
        u8g2_DrawStr(&u8g2, 32, 47, "FI-UNER");
        u8g2_DrawStr(&u8g2, 18, 63, "v1.1-2026");
    } while (u8g2_NextPage(&u8g2));
    sleep_ms(2000);
}

void interface_led_set(bool on) {
    gpio_put(PIN_LED, on);
}

void interface_led_toggle(void) {
    if (settings.led_enabled) {
        gpio_xor_mask(1u << PIN_LED);
    }else  {
        gpio_put(PIN_LED, 0);
    }
}

// Non-blocking buzzer state
static bool beep_active = false;
static absolute_time_t beep_end_time;

// Heartbeat state (visual + audible)
static volatile bool heartbeat_req = false;
static bool heartbeat_active = false;
static absolute_time_t heartbeat_end_time;

// USB Activity tracking
static absolute_time_t usb_activity_end_time;
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

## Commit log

2026-09-18 Se inicia repo
    feat: inicializar estructura del proyecto e integrar firmware 01_pico_ecg
    - Configuración de repositorio: .gitignore optimizado (Python, LTSpice, C/C++ y KiCad) y licencia MIT.
    - Documentación principal (README.md) con arquitectura, hoja de ruta y guías de inicio rápido.
    - Firmware: integración del módulo inicial 01_pico_ecg (reproductor clínico Flash/RAM), componentes comunes y matriz comparativa.
    - Software: suite modular en Python (GUI, comunicaciones, procesamiento y requirements.txt).
    - Simulaciones: scripts de análisis y entorno para modelos LTSpice.
    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
2026-09-18 Se agrega hardware v1.0.0
    feat(hardware): incorporar proyecto KiCad pico_ecg y archivos de fabricación
    - Proyecto unificado KiCad: esquemático (.kicad_sch), diseño de PCB (.kicad_pcb) y archivo de proyecto (.kicad_pro).
    - Librería local de huellas y componentes en pico_ecg.pretty.
    - Estructura y assets de producción: archivos Gerber, modelos 3D, lista de materiales (BOM) e imágenes.
    - Documentación de hardware y guía de capas en hardware/README.md.
    [DGK0008A.stp, Lipo Charger - With Load Protection.stp, OLED 0.96_ V2.0.step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]
2026-09-18 Se agregan simulaciones
    feat(simulaciones): incorporar modelos LTSpice, estímulos PWL y análisis gráfico
    - Circuitos analógicos: simulación transitoria (filter_pwm.asc), respuesta en frecuencia AC (filter_pwm_ac.asc) y circuito de sensado de marcapasos (pace_input_circuit.asc).
    - Estímulos PWL: perfiles temporales de bioseñal ECG (ecg_pwl.txt, ECG-LTSPICE.txt) y tren de pulsos con decaimiento RC (pace_pulse_train_rc.txt).
    - Script de procesamiento (data_graph.py) con submuestreo acelerado y generación de gráficos comparativos (Figure_1.png, Figure_2.png).
    - Documentación detallada y flujo de trabajo paso a paso en simulaciones/README.md.
    - Regla en .gitignore para excluir exportaci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
2026-09-18 Script de procesamiento de señales para generación de headers.
    "feat(datasets): incorporar registros clinicos LUDB, script de procesamiento y tablas C" -m "- Base de datos clinica: registros de 12 derivaciones de Lobachevsky (PhysioNet) en datasets/raw/.
    - Pipeline de conversion: notebook generacion_de_senales.ipynb con deteccion de QRS y empatamiento de ciclos para bucle continuo.
    - Tablas C (.h): senales listas para firmware en datasets/header_arrays/ (ritmo sinusal, bradicardia y fibrilacion auricular).
    - Reglas en .gitignore para ignorar modelos de deep learning (*.h5) y cache de Jupyter (.ipynb_checkpoints).
    - Documentacion completa de formatos y datos en datasets/README.md."
    [ludb.csv]
2026-09-18 Corrida de prueba de script, generación de N_65.h
2026-09-18 Se agega software de control
    feat(software): integrar suite de monitoreo ECG_GUI v1.2.0 y script de compilacion" -m "- Aplicacion de escritorio en Tkinter + Matplotlib (ecg_gui.py): conexion USB a 921600 baudios, decodificacion 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
    - Modulo para banco de marcapasos: calibracion de umbrales atriales/ventriculares (pace-sense) y periodos refractarios.
    - Grabacion y utilidades: registro continuo a CSV, capturas PNG en alta resolucion y terminal de datos con visor hexadecimal.
    - Script de automatizacion PyInstaller (build_exe.bat y ECG_GUI.spec) para generar ejecutable portatil de Windows.
    -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
2026-09-18 feat(firmware): integrar modulo 01_pico_ecg para RP2040/RP2350
    - Reproductor clinico: salida analoga PWM a 100 kHz para 9 derivaciones (RA, LA, LL, V1-V6) a partir de registros en Flash.
    - Interfaz local y menu OLED: integracion de librerias GEM y u8g2 con control por rotary encoder y feedback audiovisual de onda R (buzzer/LED).
    - Consola CLI y telemetria: comandos de control texto USB CDC (115200 baud) y streaming binario de precision (500 SPS).
    - Optimizacion del arbol: limpieza de assets innecesarios en u8g2, reubicacion de pwm_gen.py a simulaciones/scripts y actualizacion de .gitignore.
2026-09-22 Actualización de Readmes, se mueve u8g2 y GEM a common.
2026-09-22 Se agrega documentación base de los modelos de generación.
2026-09-22 Edición de formato de Readmes
2026-09-22 Se actualiza Readme GUI con imagen. Se corrigen problemas de comunicación y graficación de curvas.
    [ecg_gui.py, pico_ecg.c]
2026-09-22 Se incorporan STLs de gabinete
    [base.stl, frente.stl]

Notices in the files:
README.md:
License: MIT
